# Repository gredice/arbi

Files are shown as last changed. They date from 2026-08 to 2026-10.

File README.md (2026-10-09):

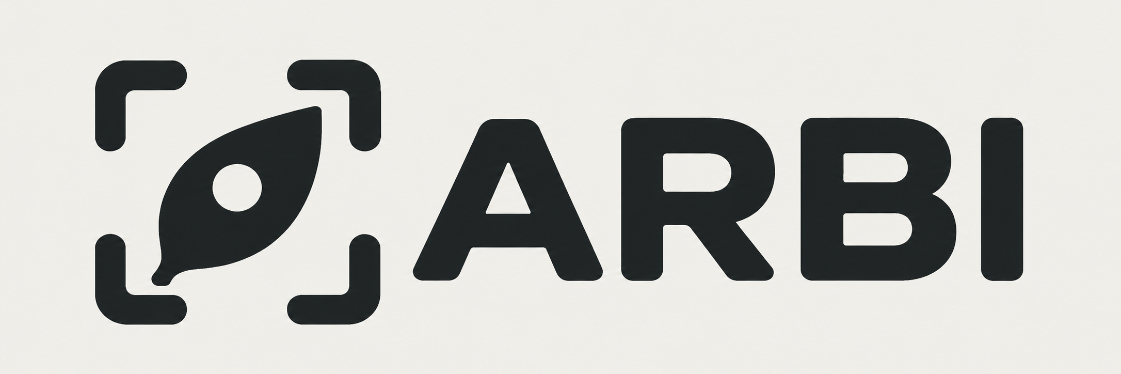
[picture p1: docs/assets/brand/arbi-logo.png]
ARBI Garden Focus logo: a leaf and lens inside a viewfinder


# ARBI

The Automatic Raised Bed Imaging system, is an open engineering project for a four-cable outdoor camera robot. This GitHub repository is the sole source of truth for the project. Its committed files and Git history define the documentation, parametric OpenSCAD models, bill of materials, software, tests, and design decisions; GitHub issues and pull requests hold the corresponding work and review history.

The current material is a **concept and design baseline**. It is not evidence of a built, certified, or safe installation. See the [design status](docs/project/design-status.md) and [safety case](docs/system/safety-case.md) before using any design information.

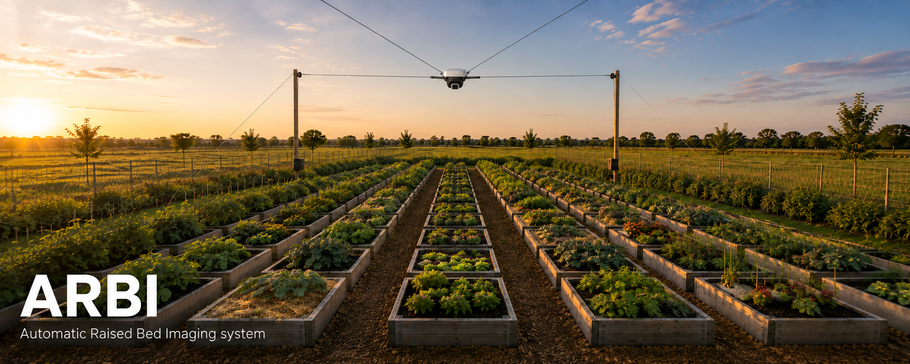
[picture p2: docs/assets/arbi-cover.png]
ARBI Automatic Raised Bed Imaging system over raised garden beds


*Scenic concept imagery using the [selected payload design language](docs/project/industrial-design.md); not a built installation.*

## Start here

- [Engineering documentation](docs/README.md)
- [Goals and V1 scope](docs/project/goals-and-v1-scope.md)
- [System architecture](docs/system/architecture.md)
- [Current design status](docs/project/design-status.md)
- [Industrial design conventions](docs/project/industrial-design.md)
- [Official logo and brand guide](docs/project/brand-identity.md)
- [Repository source-of-truth policy](docs/project/repository-source-of-truth.md)
- [Hardware and OpenSCAD sources](hardware/README.md)
- [BOM data and generated reports](bom/README.md)
- [Contributing](CONTRIBUTING.md)

## Repository map

- `docs`: requirements, architecture, physical assemblies, operations, decisions, and evidence policy.
- `hardware`: canonical OpenSCAD sources, shared modeling helpers, model metadata, and hardware-specific notes.
- `bom`: canonical part, assembly, supplier, offer, destination, and build data plus generated reports.
- `packages/arbi-bom`: BOM schemas, deterministic landed-cost calculation, generation, and validation.
- `apps/arbi-docs`: public site at [arbi.gredice.com](https://arbi.gredice.com), compiled from the files above at build time.
- `scripts`: repository-level validation that does not belong to one package.
- `.github`: public contribution templates and secret-free continuous integration.

The documentation is organized by physical assembly: [corner support set](docs/assemblies/corner-station/README.md), [camera pod](docs/assemblies/camera-pod/README.md), [dock](docs/assemblies/dock/README.md), [control cabinet](docs/assemblies/control-cabinet/README.md), and [site installation](docs/assemblies/site-installation/README.md). The [winch set](docs/assemblies/winch/README.md) is a corner-support subassembly and owns the four lines, with a shared [positioning-line specification](docs/assemblies/positioning-lines/README.md). Mechanical parts, electronics, wiring, fasteners, printed parts, software interfaces, tests, and maintenance information belong to their owning assembly rather than to component-type subsystems.

## Local setup

Requirements:

- Node.js `>=24` (`.nvmrc` pins the current development release)
- Corepack and the pnpm version pinned in `packageManager`
- OpenSCAD `2021.01` for local geometry compilation; static CAD validation still runs when OpenSCAD is absent

```bash
corepack enable
pnpm install
pnpm docs:check
pnpm bom:check
pnpm cad:check
pnpm lint
pnpm typecheck
pnpm test
pnpm build
```

`pnpm cad:check` compiles every registered model when `openscad` is available. CI requires OpenSCAD and always performs compilation. Generated STL, 3MF, and CSG files are derived artifacts and are not committed.

Use `pnpm bom:generate` after changing canonical BOM inputs. Generated Markdown and JSON reports are tracked so GitHub readers can inspect a deterministic build calculation. CI rejects missing or stale generated reports.

See [WORKSPACE.md](WORKSPACE.md) for boundaries, commands, generated artifacts, and the planned software layout.

## Planned monorepo growth

Deployable software will be added only with an implemented, testable slice. Expected destinations are:

- `apps/arbi-simulator`: simulator executable or interface;
- `apps/arbi-edge-controller`: local orchestration and control adapter;
- `apps/arbi-cloud`: remote request, telemetry, and image integration if required;
- `apps/arbi-pod-firmware` and `apps/arbi-control-cabinet-firmware`: hardware targets when their toolchains and boundaries are selected;
- `packages/arbi-protocol`, `packages/arbi-control`, and `packages/arbi-simulation-core`: shared contracts and pure logic when reuse is real.

Empty placeholder applications are intentionally omitted. The [simulator decision](docs/decisions/0004-simulator-boundary.md) preserves the required contract boundary without claiming an implementation exists.

## Contributing and safety

Contributions are welcome through GitHub issues and pull requests. Changes that affect loads, mains wiring, motion, line clearance, docking, control authority, or fault behavior must state their safety impact and validation evidence. CAD compilation, simulation, bench testing, installed-system testing, and safe public operation are separate evidence levels.

Read [CONTRIBUTING.md](CONTRIBUTING.md), [GOVERNANCE.md](GOVERNANCE.md), [SECURITY.md](SECURITY.md), and the [Code of Conduct](CODE_OF_CONDUCT.md) before contributing.

## License

Unless an individual file explicitly states otherwise, all source code, OpenSCAD hardware sources, documentation, BOM files, and other repository materials are licensed under the [GNU Affero General Public License v3.0 only](LICENSE). This matches the Gredice monorepo license and keeps the planned V1 merge path explicit.

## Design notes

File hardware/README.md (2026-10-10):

# ARBI hardware sources

This directory contains the canonical parametric OpenSCAD sources for custom ARBI parts and illustrative models of catalog items. Every current model is a **concept-unvalidated** starting point: it has not been proven dimensionally compatible, printable, structurally adequate, weather-resistant, or safe for an installed system.

The shared helpers use [BOSL2 v2.0.766](vendor/BOSL2/README.md), vendored with its
license, upstream commit and source hashes. No global library installation is
required. The guide documents current uses, anchoring and rounding conventions,
portable source packs and the upgrade process.

## Model index

The machine-readable registry is [models.json](models.json). It declares stable model IDs, design revisions, source entrypoints, owning assemblies, documentation, status, and release output names.

| Model | Assembly | Revision | Purpose |
| --- | --- | --- | --- |
| `winch-drum` | [Winch](assemblies/winch/README.md) | `2.1.0` | Segmented drum assembly reference |
| `winch-drum-passive-1/2`, `winch-drum-powered-1/2/3` | [Winch](assemblies/winch/README.md) | `0.1.0` | Five variant-specific grooved body sections |
| `winch-drum-flange`, `winch-drum-flange-right`, `winch-drum-clamp-half`, `winch-drum-tail-clamp`, `winch-drum-alignment-pin` | [Winch](assemblies/winch/README.md) | `0.1.0` | Shared drum fabrication components |
| `winch-mount` | [Winch mount](assemblies/winch/mount.md) | `0.1.0` | Passive/powered mount assembly and base drilling reference |
| `winch-bearing-lower`, `winch-bearing-cap`, `winch-motor-stand`, `winch-coupling-guard` | [Winch mount](assemblies/winch/mount.md) | `0.1.0` | Bearing supports, adjustable motor stand and coupling cover |
| `camera-pod-envelope` | [Camera pod](assemblies/camera-pod/README.md) | `0.1.0` | Non-manufacturing pod and motion keep-out reference |
| `camera-pod-assembly` | [Camera pod](assemblies/camera-pod/README.md) | `0.3.5` | Canonical non-manufacturing enclosed camera-pod reference |
| `camera-pod-spider` | [Camera pod](assemblies/camera-pod/README.md) | `0.1.0` | Four-line load-interface spider concept |
| `camera-pod-electronics-mount`, `camera-pod-docking-stud`, `camera-pod-line-strain-relief` | [Camera pod](assemblies/camera-pod/README.md) | `0.1.0` | Fixed electronics plate, mushroom stud and line fairleads |
| `camera-gimbal-base`, `camera-gimbal-yoke`, `camera-gimbal-camera-plate`, `camera-gimbal-rain-cap`, `camera-gimbal-optical-hood` | [Camera pod](assemblies/camera-pod/README.md) | `0.1.0` | Two-axis gimbal fabrication set |
| `dock-funnel` | [Dock](assemblies/dock/README.md) | `0.1.0` | Passive conical alignment funnel concept |
| `dock-nest` | [Dock](assemblies/dock/README.md) | `0.1.0` | Pod locating nest and mounting plate concept |
| `top-pulley-keeper` | [Corner station](assemblies/corner-station/README.md) | `0.1.0` | Line-retention keeper around the top pulley concept |

Fabrication models identify their canonical BOM part IDs in the registry. The winch-drum assembly, winch-mount, camera-pod envelope, and camera-pod assembly are `reference` artifacts with no BOM part IDs and export CSG. Individual drum, mount, camera-pod chassis, and gimbal components export fabrication STL and map to their BOM parts. All models remain concept-unvalidated.

Every BOM catalog item has at least one active model. Purchased items, materials,
consumables and custom items without manufacturing sources have `visualization`
STLs. These carry explicit `geometry.status: approximate`, dimension assumptions
and rework requirements in the registry, source header and assembly README. Their
shape is not yet fully defined. They need supplier drawings or measurements and
model rework before fit, clearance or fabrication decisions. Visualization STL
does not establish a manufacturing source, even for a planned custom item.
Assortments show samples rather than pack contents; cables show samples rather
than installed length or routing. Shared purchasing samples live in
[shared procurement stock](assemblies/shared-procurement-stock/README.md).

## Validation

From the repository root:

```bash
pnpm cad:check
pnpm cad:check -- --require-openscad
```

The first command always validates registry metadata against its JSON Schema, checks source files, documentation links, relative OpenSCAD dependencies, bidirectional BOM fabrication-source traceability, and the exact pinned OpenSCAD version when the CLI is present. It compiles all registered models when `openscad` is installed. The second command requires the CLI and compilation and is the CI path. Both compile paths require OpenSCAD `2021.01`; a different installed version fails explicitly so model outputs are not presented as reproducible across an untracked toolchain change.

Compilation writes declared STL fabrication and visualization meshes and CSG reference artifacts into a temporary directory and removes it afterward. Generated STL, 3MF, CSG, and bulk render output are not committed. A successful compile proves only that source geometry can be evaluated.

## CAD downloads

[GitHub Releases](https://github.com/gredice/arbi/releases) publishes a complete CAD snapshot whenever OpenSCAD sources, the model registry, booklet inputs or CAD publication tooling change on `main`. New releases use `cad-vMAJOR.MINOR.PATCH`, starting at `cad-v0.1.0` and automatically incrementing the highest published or reserved patch version. A manual workflow dispatch can request a higher minor or major version. These are snapshot versions; each model keeps its own design revision and evidence status. Existing `cad-<full commit SHA>` releases remain historical records.

Each release includes every registered STL fabrication part, approximate visualization STL, CSG reference assembly, hardware source ZIP, all three assembly booklets and packs, the complete CAD preview pack, and SHA-256 checksums. `cad-release.json` records the exact source commit, model revisions and CAD/booklet/preview input hashes. Publication first uploads a draft, then publishes the complete release. Retrying a published source commit reuses its immutable version and retries the site refresh. Latest follows source commit ancestry, so rerunning an older commit cannot replace a newer source release even if it receives a higher snapshot version.

Production site builds require the release inputs to match their checkout and all registered outputs to be present. Publishing Latest calls the required `ARBI_SITE_DEPLOY_HOOK` secret and verifies that [arbi.gredice.com](https://arbi.gredice.com) serves the current release or a subsequent one within ten minutes. A missing hook, failed request or failed verification fails the workflow visibly; rerun it to retry. While new geometry is being built, a premature Vercel production build fails and the last successful site remains live until the release-triggered rebuild succeeds. A release does not establish that a part is physically safe to build or install.

To keep compiled files locally, pass an empty output directory: `pnpm cad:check -- --require-openscad --output-dir /path/to/empty-directory`.

## Adding a model

1. Read [conventions.md](conventions.md).
2. Put reusable modules in `lib` and assembly-owned entrypoints in `assemblies/<assembly>`.
3. Add one registry entry per intended output in `models.json`.
4. Document purpose, default parameters, interfaces, known omissions, and required validation beside the model.
5. Run the required CAD check and review the generated geometry visually before proposing a release.

The system requirements and evidence status live in the matching documents under [`docs/assemblies`](../docs/assemblies).

The [winch mount family](assemblies/winch/mount.md) adds a bearing lower, bearing
cap, motor stand and coupling cover (0.1.0), with a passive/powered assembly
reference. Metal base stock is a drilling proposal, not a printed release part.

## Archived models

`models.json` separates active `models` from `archivedModels`. Archived entries retain stable IDs, revisions, evidence status, source paths, an archive reason and current replacement IDs. They have no BOM ownership, active inventory count, individual release mesh, preview or fabrication download. CAD validation still checks their source/includes so historical references cannot silently break.

The camera-pod archive covers the original concept kit and keep-out, six dry bench-only alternatives, and the retired fixed fairing, tilt-servo boot and rear camera cowl. The compact `camera-pod-integrated-deck` is current; `camera-pod-electronics-deck` is the dry bench alternative. The shared spider, spacers, pan mount and horn retainers remain active. Docking-stud and line-termination concepts have no selected replacement; archiving them does not resolve those interfaces.

The explicit dry bench booklet opts into only the archived entries marked `alternativeConfiguration: camera-pod-bench`; it is labeled as an alternative and does not add parts to the current compact enclosure BOM or assembly. The enclosure exports 13 fabrication models (12 installed types plus the optional servo fit coupon) and installs 16 printed pieces. Other committed model families retain their documented optional configurations and variants; an unmerged replacement proposal does not supersede them.

## Camera-pod naming compatibility

All current camera-pod CAD IDs, source/module names and new booklet artifacts use `camera-pod`. The [alias map](model-aliases.json) records the former `payload-*` public IDs, including both retired assembly aliases for the single `camera-pod-assembly` reference. Old website part links redirect permanently to their current active or archived detail page. Fabrication revisions and installed quantities do not change with this rename; BOM part IDs remain stable.

Dated inspection JSON and committed PDF/ZIP snapshots retain the observed model names, filenames and hashes. Their names identify historical evidence, and do not register duplicate current models. New CAD releases and enclosure/bench booklets are regenerated from the canonical sources. Generic software message payloads retain their protocol meaning.

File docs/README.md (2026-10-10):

# ARBI engineering documentation

ARBI is an outdoor four-cable camera robot for repeatable images of raised beds. This documentation is organized by physical assembly so that each assembly owns its mechanics, electronics, cabling, fasteners, printed parts, software, tests, and maintenance information.

The committed material is a **design baseline**, not proof of a built or safe installation. Values described as targets or starting points remain unverified until an acceptance record is committed and linked from the relevant document. The repository and its GitHub records are the project's only authority; see the [repository source-of-truth policy](project/repository-source-of-truth.md).

## Start here

- [Goals and V1 scope](project/goals-and-v1-scope.md)
- [Current design status](project/design-status.md)
- [Industrial design conventions](project/industrial-design.md)
- [Official logo and brand guide](project/brand-identity.md)
- [System architecture](system/architecture.md)
- [Site geometry](system/site-geometry.md)
- [Interfaces and operating states](system/interfaces-and-operating-states.md)
- [Safety case](system/safety-case.md)
- [Local safety interface matrix](system/local-safety-interface-matrix.md)
- [Prototype and commissioning plan](operations/prototype-and-commissioning.md)
- [Repository source-of-truth policy](project/repository-source-of-truth.md)

## Physical assemblies

- [Site installation](assemblies/site-installation/README.md)
- [Corner support set](assemblies/corner-station/README.md), including the [winch set](assemblies/winch/README.md) and its ordinary/powered positioning lines
- [Camera pod](assemblies/camera-pod/README.md)
- [Dock](assemblies/dock/README.md), with a proposed [compact-pod interface package](assemblies/dock/design-package.md),
  [bench plan](assemblies/dock/bench-test-plan.md) and [blank acceptance record](assemblies/dock/acceptance-record.md)
- [Control cabinet](assemblies/control-cabinet/README.md)

## Shared assembly specifications

- [Positioning-line specification](assemblies/positioning-lines/README.md): construction, terminations, inspection and replacement of winch-owned lines

## Components and procurement

- [Bill of materials](../bom/README.md)
- [Individual BOM item pages](../bom/generated/parts/README.md)

## Operations

- [Imaging and calibration](operations/imaging-and-calibration.md)
- [Weather, parking, and maintenance](operations/weather-parking-and-maintenance.md)
- [Prototype and commissioning](operations/prototype-and-commissioning.md)

## Decision records

- [ADR-0001: Organize engineering information by physical assembly](decisions/0001-physical-assembly-taxonomy.md)
- [ADR-0002: Treat OpenSCAD files as canonical model sources](decisions/0002-openscad-canonical-sources.md)
- [ADR-0003: Separate parts, assembly quantities, and supplier offers](decisions/0003-bom-separation.md)
- [ADR-0004: Share contracts between hardware control and simulation](decisions/0004-simulator-boundary.md)
- [ADR-0005: Software architecture and deployment boundaries](decisions/0005-software-architecture-and-deployment.md)
- [ADR-0006: Local safety authority and instrumentation](decisions/0006-local-safety-authority-and-instrumentation.md)
- [ADR-0007: Integrated product design](decisions/0007-integrated-product-design.md)
- [ADR-0008: Edge host and bounded local transport](decisions/0008-edge-host-and-local-transport.md)
- [ADR-0009: Compact integrated camera pod packaging](decisions/0009-compact-integrated-camera-pod.md)
- [ADR-0010: Corner support and winch-line ownership](decisions/0010-corner-support-and-winch-line-ownership.md)

## Software evidence

- [Transport capability review and bounded local recovery experiment](evidence/software-transport-feasibility.md)
- [Protocol 1.0 contracts, semantic rules and host reference-test boundary](software/protocol.md)
- [Configuration 1.0, calibration identity and transactional apply/rollback reference boundary](software/configuration.md)
- [Authorized site commissioning, multi-device staging and deliberate recovery](software/commissioning.md), with [host evidence](evidence/commissioning.md)
- [Mobile data accounting 1.0 contracts, boundary rules and executable worked fixtures](software/mobile-data-accounting.md)
- [Device transfer instrumentation, durable raw counters and explicit Linux/router coverage](software/device-traffic-metering.md), with [host evidence](evidence/device-traffic-metering.md)
- [Durable usage ingestion, billing-period rollups and explicit accounting uncertainty](software/usage-rollups.md), with [host evidence](evidence/usage-rollups.md)
- [Edge transfer budgets, essential traffic bounds and verified artifact recovery](software/transfer-budgets.md), with [host evidence](evidence/transfer-budgets.md)
- [Cross-runtime reference vectors, independent host consumers and offline workspace checks](software/reference-fixtures.md)
- [Scenario 1.0 contracts, deterministic offline runner and independent host evidence](software/scenarios.md)
- [Bounded plant/module model 1.0, virtual sensors and independent host evidence](software/bounded-plant-model.md)
- [Gredice identity, site permissions and executable request authorization boundary](software/site-authorization.md)
- [Audit 1.0 vocabulary, privacy and evidence semantics](software/audit-events.md)
- [Deferred recording, playback, custody and retention activation policy](software/recording-policy.md)
- [Transactional audit admission, SQLite spool and deduplicated ingestion](software/audit-durability.md)
- [Release/update 1.0 manifests, mixed-version paths and pure recovery reference](software/release-updates.md)
- [Gated web builds, immutable Linux application releases and read-only dashboard catalog](software/software-publication.md)
- [Device enrollment, inventory and credential lifecycle with isolated PostgreSQL evidence](software/device-enrollment.md)
- [Image metadata, private Blob direct grants, lifecycle cleanup and isolated PostgreSQL/HTTP evidence](software/image-storage.md)
- [Durable cloud command jobs, exclusive manual leases and isolated PostgreSQL/HTTP evidence](software/command-jobs.md)
- [Current state, bounded telemetry/event history and configured assembly inventory](software/telemetry-history.md), with [host evidence](evidence/telemetry-history.md)
- [Outbound realtime routing, scoped Ably SDK tokens and commit-safe authoritative recovery](software/realtime-recovery.md), with [host evidence](evidence/realtime-recovery.md)
- [Authenticated user/engineering dashboard shell, explicit synthetic test provider and setup](software/dashboard-shell.md), with [dated source/hosted evidence](evidence/dashboard-shell.md)
- [Supervised edge runtime, local framing and diagnostic authority](software/edge-runtime.md), with [development-host evidence](evidence/edge-runtime-prototype.md)
- [Local manual-control fences and independent deadman](software/manual-control.md), with [host/simulation evidence](evidence/manual-control.md)

## Evidence language

These labels are used throughout the documentation:

- **Requirement** — behavior or constraint the design must satisfy.
- **Baseline** — the current V1 design choice recorded in the repository.
- **Target** — a value the design aims to achieve but has not yet demonstrated.
- **Starting point** — an initial test value that must be tuned from measured results.
- **Unverified** — a claim or selection that still needs analysis, inspection, or testing.
- **Deferred** — intentionally outside the first prototype or V1 baseline.
- **Validated** — supported by a named test record, calculation, or inspection result committed to the repository.

Do not change a claim to **Validated** in prose alone. Link the evidence and record the tested revision, configuration, conditions, equipment, result, and reviewer.

## Documentation ownership

Cross-discipline item types are not separate subsystems. A fastener used on a winch belongs to the winch assembly; a cable from the cabinet to a corner has named endpoints and an owning interface. Shared standards may describe conventions, but the assembly documentation owns quantities, fit, routing, acceptance, and maintenance.

Design decisions belong in ADRs. Work items and unresolved questions belong in GitHub issues, with links back to the affected document. Procurement data belongs in the repository BOM rather than being copied into prose. Private notes, chats, external pages, spreadsheets, and dashboards are not project records.

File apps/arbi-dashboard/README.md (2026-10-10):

# ARBI dashboard and HTTP boundary

This Next.js app implements the [authenticated dashboard shell](../../docs/software/dashboard-shell.md) for [#39](https://github.com/gredice/arbi/issues/39), simulation-only [device enrollment and inventory boundary](../../docs/software/device-enrollment.md) for [#21](https://github.com/gredice/arbi/issues/21), and [image metadata/private storage boundary](../../docs/software/image-storage.md) for [#22](https://github.com/gredice/arbi/issues/22). It contains working HTTP handlers, protected PostgreSQL migrations, identity/proof verification, a Vercel private Blob SDK adapter and lifecycle tests. The [durable command job and exclusive manual lease boundary](../../docs/software/command-jobs.md) implements #28. [Outbound realtime and authoritative recovery](../../docs/software/realtime-recovery.md) implements the source/host slice of #29. Detailed diagnostics, live provider provisioning, live media and physical device adapters remain separate work.

The shell serves site-scoped user/engineering pages and protected `/api/sites/:siteId/dashboard/:view` reads. [Setup, contract, isolated provider and browser commands](../../docs/software/dashboard-shell.md) describe the boundary; [source/hosted evidence](../../docs/evidence/dashboard-shell.md) keeps test deployment separate from production. Ordinary starts remain unconfigured. The explicit isolated test provider uses current PostgreSQL sessions/memberships and the committed bounded plant model; it never grants commands or live-device authority.

The mounted route is `/api/sites/:siteId/enrollment/:action`. An unconfigured build returns a redacted `503`; it never installs a fixture identity provider or an in-memory registry by default. Trusted server composition uses [createEnrollmentServer](src/enrollment/server.ts) with the accepted Gredice identity/current directory/resource resolver, approved browser origins and a migrated database, then [configureEnrollment](src/enrollment/runtime.ts). The resource resolver and directory are current server-side adapters, never body-supplied roles or site claims. This initial slice rejects production and hardware scope.

Media routes are `/api/sites/:siteId/media/:action` and `/api/sites/:siteId/images/:imageId/:action`; they also fail closed until explicitly installed via [createMediaServer](src/media/server.ts)/[configureMedia](src/media/runtime.ts). The service provides strict upload metadata, retry-safe direct PUT grants, idempotent verified completion, original/thumbnail access, revocation records and repeatable deletion/cleanup. [Media documentation](../../docs/software/image-storage.md) specifies exact JSON bodies, trusted capture provenance, signed URL expiry/revocation limits, stored-payload accounting, operational cleanup/retention requirements and remaining live gates. Apply [0002-media.sql](migrations/0002-media.sql) explicitly with `pnpm --filter @arbi/dashboard db:migrate:media` and privately supplied `ARBI_MEDIA_DATABASE_URL`; `0001` and its command are unchanged. Provision authoritative media-site bindings separately; never derive ownership from request claims or enable fixture fallbacks.

[postgresDatabase](src/enrollment/store.ts) uses a server-side `pg.Pool` for the selected Neon PostgreSQL boundary. Configure pooled connections with a bounded connection timeout; no provider URL or credential is supplied in this repository. Run the [migration](migrations/0001-enrollment.sql) explicitly via `pnpm --filter @arbi/dashboard db:migrate` with `ARBI_ENROLLMENT_DATABASE_URL` supplied privately. No migration or commissioning happens during build/start. Provision the initial simulated inventory through the protected `simulationRegistry`/`PostgresRegistryStore.provision` server interface using validated configuration and the account from the authoritative site catalog. Existing rows cannot be overwritten by bootstrap.

```sh
pnpm install --frozen-lockfile
pnpm --filter @arbi/protocol build
pnpm --filter @arbi/gredice build
pnpm --filter @arbi/dashboard lint
pnpm --filter @arbi/dashboard typecheck
pnpm --filter @arbi/dashboard test
pnpm --filter @arbi/dashboard test:postgres
pnpm --filter @arbi/dashboard build
pnpm --filter @arbi/dashboard test:http
```

The ordinary suite uses embedded PostgreSQL (PGlite), temporary synthetic configuration, ephemeral device keys and a loopback HTTP Blob fixture that exercises the real SDK without cloud credentials. The separate `test:postgres` requires `pg_config`, `initdb`, `pg_ctl` and local socket/loopback access. It creates/removes its own temporary PostgreSQL cluster, disables TCP listening, and tests independent connections, migration preservation and transaction rollback for enrollment and media. After build, `test:http` starts/stops its own loopback Next.js server and verifies unprovisioned enrollment/media responses stay redacted and fail closed. CI invokes all three. The ordinary suite marks host-specific tests skipped unless the dedicated launcher supplies its isolated socket; this is not a substitute for running `test:postgres`.

Ordinary fixture files run sequentially to avoid competing database startup starving bounded loopback requests. This finite test process also disables **WebAssembly code** garbage collection with `--no-wasm-code-gc`: Node 24.15.0 Linux CI aborted in V8's `UnregisterWasmAllocation` with `jit_page_->allocations_.erase(addr) == 1`. The signature matches [Node issue #66366](https://github.com/nodejs/node/issues/66366) and the [upstream V8 wrapper lifetime fix](https://github.com/v8/v8/commit/9b8ca54d5a). This is a test-only workaround that retains compiled Wasm code until process exit; JavaScript garbage collection, assertions and request deadlines remain unchanged. Remove the flag after the pinned Node release includes the fix and repeated Linux fixture runs pass without it. Application `dev`/`start`/`build` and the native PostgreSQL/HTTP launchers do not use this flag; PGlite is a development dependency.

`pnpm --filter @arbi/dashboard start` serves a built, fail-closed app. Source tests and local database checks do not establish live Gredice/Neon provisioning, Vercel team deployment, power-loss durability, installed commissioning, safe actuation or physical acceptance. Those gates remain unverified.

## Durable audit foundation

The [audit adapter](src/audit/server.ts) adds signed device ingestion at `/api/sites/:siteId/audit/ingest`, transactional cloud intent/authorization/outbox admission and protected append-only history. It requires explicit server composition with current enrollment and an independently trusted event-ID evidence resolver; missing configuration returns 503. Device ingestion remains simulation-only under current enrollment. Apply additive `0003-audit.sql` after unchanged 0001/0002 with `pnpm --filter @arbi/dashboard db:migrate:audit` and operator-only migration credentials. Never use migration ownership as the application role.

[Audit durability](../../docs/software/audit-durability.md) owns roles, replay/clock/gap semantics, checkpoint/backup threat limits and host evidence. Shared [SQLite local APIs](../../packages/arbi-audit/README.md) remain independent of edge job orchestration. `test:postgres` preserves independent enrollment/media suites and runs native audit tests in a separate database within its fresh socket-only cluster. This does not deploy provider resources, enable recording or clear physical safety gates.

## Durable command jobs and manual sessions

Mounted `/api/sites/:siteId/jobs/:action` handlers implement persisted intent/status, exclusive fenced human leases, signed receiver snapshots, bounded device polling and immutable protocol outcome receipts. [createJobsServer](src/jobs/server.ts)/[configureJobs](src/jobs/runtime.ts) require explicit trusted current identity/resource/session authorization and migrated storage. Missing configuration denies every action. Apply additive [0004-jobs.sql](migrations/0004-jobs.sql) after unchanged 0001/0002/0003 via `db:migrate:jobs` with privately supplied `ARBI_JOBS_DATABASE_URL`. Admission uses the existing transactional audit/outbox hook.

[Command job documentation](../../docs/software/command-jobs.md) specifies exact bodies, resolver requirements, restart/clock/fence semantics, cancellation versus independent stop receipts, status provenance and remaining gates. Native `test:postgres` runs its independent-connection/crash/replay/rollback proof; built `test:http` checks all mounted job/lease actions fail closed. This is a simulation-only cloud boundary, with no broker, local job orchestration, provider provisioning or physical enablement.

## Outbound realtime recovery

Mounted `/api/sites/:siteId/realtime/:action` supports human attach/recover and signed current-device attach/recover. Explicit [server composition](src/realtime/server.ts)/[runtime installation](src/realtime/runtime.ts), current authorization, migrated storage and private Ably SDK adapter are required. Apply additive [0005-realtime.sql](migrations/0005-realtime.sql) after 0001–0004 with `db:migrate:realtime`; configure bounded operator `realtime:maintain` scheduling separately. [Semantics, roles, limits and exact external gates](../../docs/software/realtime-recovery.md) and [host evidence](../../docs/evidence/realtime-recovery.md) distinguish source/SDK fixtures/native PostgreSQL from actual Ably/Neon/Vercel/mobile acceptance. Build the edge consumer before running native `test:postgres`; root `pnpm test --concurrency=1` and CI already build it. No fixture server or identity is a deployment default.

The opt-in [browser consumer](src/realtime/browser-consumer.ts), [HTTPS adapter](src/realtime/browser-http.ts) and [Ably browser subscription](src/realtime/browser-ably.ts) use the same authoritative API. Trusted composition supplies the current ARBI bearer; page teardown aborts recovery and clears state. Hints coalesce, replay gaps reset, broker downtime permits bounded HTTPS recovery, and request/admission/application-byte budgets apply. The shell does not start this client by default. `pnpm --filter @arbi/dashboard test:browser` includes actual Chromium/SDK/native PostgreSQL recovery and revocation checks alongside the shell tests; install the pinned Chromium with `pnpm --filter @arbi/dashboard exec playwright install chromium` first.

## Current telemetry and bounded history

The [telemetry adapter](src/telemetry/server.ts) mounts signed device ingestion and protected current/history/configured-assembly inventory queries at `/api/sites/:siteId/telemetry/:action`. It retains boot/sequence/configuration and sample provenance, visible gaps/resets, explicit unavailable/stale values, quality-separated minute/hour aggregates, full event/fault detail and small private trace attachments. Current state and replay/outbox hints commit together. Trusted server composition is explicit and simulation-only; an ordinary start returns unavailable.

Apply additive [0006-telemetry.sql](migrations/0006-telemetry.sql) after migrations 0001–0005 using `pnpm --filter @arbi/dashboard db:migrate:telemetry`. [Telemetry history](../../docs/software/telemetry-history.md) specifies API fields, retention/row/byte/request/query budgets, role grants and `telemetry:maintain` for idle sites. The ordinary and native PostgreSQL suites include the committed [telemetry evidence](../../docs/evidence/telemetry-history.md); `test:http` checks the mounted fail-closed routes. Provider provisioning and physical acceptance remain separate.

## Usage ingestion and rollups

The [usage adapter](src/usage/server.ts) mounts `/api/sites/:siteId/usage/:action` for signed bounded source-window admission, current-authority history/period reads and audited append-only corrections. It requires explicit trusted [runtime installation](src/usage/runtime.ts) and fails closed by default and in branch previews. Apply [0007-usage.sql](migrations/0007-usage.sql) after 0001–0004 with `pnpm --filter @arbi/dashboard db:migrate:usage`; keep migration ownership separate from application privileges. [Usage documentation](../../docs/software/usage-rollups.md) specifies exact request bodies, replay/overlap semantics, layer separation, UTC days, plan-timezone periods, estimated boundary allocation, rollover and hard bounds. [Host evidence](../../docs/evidence/usage-rollups.md) separates embedded SQL from native audit/concurrency checks and actual cellular/provider acceptance.

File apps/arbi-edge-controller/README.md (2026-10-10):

# ARBI edge controller

Executable **development-host prototype** for [#23](https://github.com/gredice/arbi/issues/23), implementing [ADR-0008](../../docs/decisions/0008-edge-host-and-local-transport.md). It runs only an isolated `test` realm in `simulation` mode. Diagnostic readiness never enables physical actuation, updates or recording. It implements local connection supervision and bounded state/telemetry admission; optional local jobs, commissioning and cloud recovery are described below; real firmware remains follow-up work.

## Run from the repository root

Use Node.js 24.15.0 (repository minimum 24), pinned pnpm and OpenSSL for disposable test certificates:

```sh
pnpm install --frozen-lockfile
pnpm build
pnpm --filter @arbi/edge-controller simulate
```

The process generates a private temporary certificate directory, starts two loopback test peers and prints one JSON startup record containing an ephemeral `healthPort` and fresh edge identity. Read `http://127.0.0.1:<healthPort>/healthz` and `/readyz`. Send SIGINT or SIGTERM to close sockets, cancel reconnects, stop the peers and remove temporary credentials. Keys, certificates and configuration paths are never printed. Abrupt process termination may leave its private temporary directory; remove that disposable directory locally after stopping its processes. No generated credential belongs in Git.

`/healthz` returns 200 while the process serves requests. `/readyz` returns 503 until both authenticated peers provide compatible current snapshots, and again on disconnect, expiry or shutdown. Both expose build source digest/version, protocol, new boot/session identity, exact accepted applied configuration identity, module identities, inhibits and configured capabilities. The build digest includes app sources, compiler settings, dependency lockfile, Linux service definition, protocol schemas and built protocol consumers. The historical `appliedBy` remains distinct from the current boot identity. Health binds loopback and limits connections/headers. The default runtime accepts only GET health/readiness; trusted commissioning composition can add the separately authenticated routes described below.

For externally hosted synthetic peers, a private `arbi.edge/1.0` manifest specifies the bounded applied configuration record, independently accepted configuration digest, the edge's certificate file paths and exactly two local enrollment entries. Entries bind module ID/role, loopback port, DNS certificate name and certificate SHA-256. There is no discovery of arbitrary network addresses or trust-on-first-use enrollment. `createSimulation()` in [simulation.ts](src/simulation.ts) produces the executable reference manifest from the committed protocol fixture. Invalid, oversized, unsupported, non-test or hardware configuration exits 78 before opening health or module sockets. This loader only restores a previously accepted synthetic record; optional commissioning is a separate trusted composition.

```sh
node apps/arbi-edge-controller/dist/cli.js --config /absolute/private/simulation.json
node apps/arbi-edge-controller/dist/supervisor.js --config /absolute/private/simulation.json
```

The second command is a portable child-process supervision prototype: at most five starts per minute, 250 ms retry delay on crash, no retry for exit 0 or invalid configuration (78), SIGTERM then SIGKILL after five seconds on shutdown. It has no command journal and replays no commands. Linux uses [the systemd unit](deploy/arbi-edge-controller.service), not the development supervisor. The `/opt/arbi` and `/etc/arbi-edge` paths are installation templates, not a private deployment. An operator must stage the immutable repository build and Node 24 runtime at the declared paths, create the dedicated unprivileged account, and supply private synthetic configuration/credentials before starting it. See the ADR for privileged installation, service confinement and the unfulfilled selected-host acceptance gate.

## Adapter boundary

See [the transport specification and evidence](../../docs/software/edge-runtime.md). `ModuleAdapter` connects using TLS 1.3 mutual authentication and certificate pinning. A fresh challenge, source identity, protocol, test realm/site and accepted configuration digest precede the initial snapshot. Discovery verifies existing enrollment; it cannot grant new trust. The prototype exposes only `state.resync`, authorized explicitly to the synthetic `simulation-diagnostics` service through a bounded, single-use grant. TLS host identity is never human authority. No human permission, UI mode, cloud grant or opaque object can enable actuators here.

The simulated module independently admits that diagnostic command through `@arbi/protocol`. Source/configuration/capability/cursor checks apply to received snapshots and telemetry. Configured unavailable readings retain empty capability qualities; driver encoders and line tension do not become measured data. The simulated module remains locally inhibited and its local stop function has no edge/cloud dependency. This is a source boundary demonstration, not proof of independent physical stopping or a firmware watchdog.

## Validation

```sh
pnpm --filter @arbi/edge-controller lint
pnpm --filter @arbi/edge-controller typecheck
pnpm --filter @arbi/edge-controller test
pnpm --filter @arbi/edge-controller build
pnpm protocol:check
pnpm docs:check
git diff --check
```

Tests require loopback listening, child processes and OpenSSL. Linux additionally requires `systemd-analyze` and the same Node version staged at the unit's declared `/usr/bin/node` path; CI provisions that path explicitly before verifying the unmodified unit. They use disposable synthetic credentials, the current configuration fixture and protocol message vectors. The [committed evidence record](../../docs/evidence/edge-runtime-prototype.md) identifies what was run and which Linux, hardware and physical gates remain unverified.

## Traffic metering

Optional private `metering` settings contain `spoolFile`, `maxRecords`, `maxBytes`, `maxPages` and `linuxLoopback`. Omission is explicitly `not-configured`; there is no implicit production path. Place the file in the service's private `StateDirectory=arbi-edge` when configured. The synthetic `--simulate` consumer uses temporary edge and pod SQLite files, 2,048 records/16 MiB reserved bytes/1,024 pages each, and deletes them only on fixture disposal. These starting budgets are not qualified selected-host capacity.

Authenticated module socket frames are tapped through [@arbi/traffic](../../packages/arbi-traffic/README.md); the simulated pod exercises the same library. Current endpoints and optional five-second Linux `lo` counter collection remain LAN-only. Health exposes partial application coverage, unknown UTC uncertainty, unavailable garden WAN/provider counters, and durable/volatile spool degradation. Counter/payload/provider layers remain separate. Physical actuation, readiness authorization and local stops do not depend on metering health. See [semantics](../../docs/software/device-traffic-metering.md) and [host evidence](../../docs/evidence/device-traffic-metering.md).

## Independent cloud recovery consumer

`pnpm --filter @arbi/edge-controller recover:cloud` runs [the separate diagnostic recovery executable](src/cloud-realtime/cli.ts) after build, with private protected `ARBI_CLOUD_RECOVERY_CONFIG`. [Realtime documentation](../../docs/software/realtime-recovery.md) owns exact fields, current enrollment, scoped short-lived Ably tokens, native PostgreSQL/HTTP recovery, retry/catch-up/traffic limits and the external provider/mobile gate. It does not import the local runtime, supervisor or jobs executor, cannot dispatch actuators and is never started by the existing supervisor. Snapshot/hint/job-poll receipt sends no device acceptance or completion. The [host record](../../docs/evidence/realtime-recovery.md) covers real SDK transport fixtures and a separately spawned consumer/cloud process, not a real provider account or cellular network.

## Durable local job slice

Optional bounded SQLite job storage, transactional audit intent, current local policy and an explicit bounded simulator consumer are documented in [local jobs](../../docs/software/local-jobs.md) with [host evidence](../../docs/evidence/local-jobs.md). Normal TLS enrollment remains diagnostic-only. Run the isolated reference with `pnpm --filter @arbi/edge-controller simulate:jobs --directory /tmp/arbi-isolated-jobs` after building its dependencies. Physical motion, firmware, image bytes and updates remain inhibited/unimplemented.

## Authorized commissioning

[Local commissioning](../../docs/software/commissioning.md) adds authenticated technician enrollment, independent local maintenance authorization, exact-set review, multi-device staging/activation, readiness invalidation and deliberate restart recovery. [Host evidence](../../docs/evidence/commissioning.md) covers fictional site/bed/plant framing and SIGKILL after an independent device commit. Trusted `composeCommissioning` mounts protected loopback handlers and automatically binds its inhibit to local job policy. The dashboard can read its protected identity/block-reason projection. No default runtime or private settings file creates commissioning authority. Run the explicit simulation recipe with `pnpm --filter @arbi/edge-controller simulate:commissioning --directory /tmp/arbi-isolated-commissioning`. Hardware/physical validation remains disabled.

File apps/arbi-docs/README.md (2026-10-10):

# ARBI public site

Next.js and Tailwind CSS site for [arbi.gredice.com](https://arbi.gredice.com). Its content is compiled from this repository at build time; the app holds no copies of documentation, models or BOM data.

Every page is statically generated at build time with the Next.js App Router:

| Route | Content |
| --- | --- |
| `/` | Cover with a scroll-driven teardown of the camera pod, statistics, contents and the BOM total |
| `/systems`, `/systems/[slug]` | Five physical root systems, with winch detail pages under the corner support set; each preview has numbered parts and a hover-linked inventory |
| `/systems/positioning-lines` | Permanent redirect to `/systems/corner-station`; the shared specification remains under `/docs/assemblies/positioning-lines` |
| `/systems/winch-powered` | Powered winch configuration with its own booklet pose and installed parts inventory; linked from the passive winch page |
| `/parts`, `/parts/[id]` | Every BOM item plus individual CAD components and references, grouped by owner with line-art figures, a 3D viewer, BOM links, geometry evidence and verified downloads |
| `/bom`, `/bom/[id]` | The generated BOM report and one page per catalog item |
| `/docs`, `/docs/[...slug]` | `docs/**`, `hardware/**` and `bom/README.md` rendered from Markdown with repository links mapped to site routes |
| `/downloads` | CAD release assets, archived committed booklet snapshots and per-model files with SHA-256 |

System navigation follows `parentAssemblyId`: physical roots own the numbered system links. The cover contents and Systems overview display included subassemblies beneath each parent, with configured CAD previews and parts-inventory links. The same subassembly section sits immediately below the parent system's main 3D preview. The corner system's overview shows both the pulley post head and winch previews, and its description names the three ordinary winches and one powered winch. Overview counts include the complete system with duplicate model and BOM IDs removed; prices remain on detail/BOM pages.

The [pulley post head](../../docs/assemblies/corner-head/README.md) has a `/systems/corner-head` presentation group using the existing corner-station CAD scene and a subset of its registered parts. It shares system number 01 with both winch variants. This group does not change direct BOM ownership, procurement quantities or source geometry. Parts keep their recorded direct owners, following [ADR-0010](../../docs/decisions/0010-corner-support-and-winch-line-ownership.md). Mobile navigation uses a Menu disclosure instead of a horizontally scrolling link strip; it closes after choosing a link, clicking outside or pressing Escape.

The design is the selected "Manual + Ink" direction. White manual pages use heavy rules, condensed type and booklet-style line art. Exploded views sit in full-black sections that draw the same line art inverted, with each part's role readable: white shells in pure white, the charcoal core in neutral lighter gray, bought metal in mid gray.

Code layout: `src/lib/site.ts` reads the compiled data on the server; `src/lib/markdown.ts` renders documents; `src/components/three/viewer.ts` is the three.js viewer used by the client components `CoverTeardown`, `SystemExplorer` and `PartViewer`. Links from the earlier single-page site (`#/systems/winch`) are forwarded to their routes.

Viewers show a nonblocking loading indicator while meshes arrive. Assembly parts
load independently with up to four concurrent requests and appear immediately,
including static contents previews. The camera starts from the compiled full
assembly envelope so downloading parts do not recenter the view. The camera pod
uses the booklet pack’s individual STL meshes and original millimetre transforms;
a part page downloads only its own mesh. Failed parts leave the loaded geometry
visible with an unavailable count, and leaving a page stops further queue work.

Line art combines sharp feature edges and open boundaries with camera-dependent silhouettes, so rounded surfaces keep a continuous outline while orbiting, zooming or exploding an assembly. Coplanar triangle edges stay hidden. Mesh adjacency is cached; contour buffers belong to each displayed instance and are released with the viewer.

The shaded part view uses a bounds-fitted Z-up studio with key, fill and rim
lights, filtered self shadows and a transparent floor shadow. A bundled room
environment supplies reflections for satin shells and metal parts; filmic tone
mapping keeps highlights readable. Denoised ambient occlusion adds depth to
recesses and contact points, with its resolution capped independently of the
display. The floor is excluded from CAD envelopes and
camera fitting. Lighting, shadow and environment resources are released when
switching views. Line and ink drawings keep their exact flat colors.

Embedded viewers preserve vertical touch scrolling, browser pinch zoom and
mouse-wheel page scrolling. Mouse dragging still rotates a model. The cover's
explosion follows page scrolling; assembly pages also have an explosion slider.
Four schematic suspension lines on the cover start at the spider's line holes
and extend upward out of view. They follow its exploded offset, use scene depth
for occlusion, and are excluded from CAD bounds and camera fitting.
Clicking a registered mesh opens its CAD page. The winch motor and bought
hardware open their owning BOM pages, recorded by the booklet figure manifest;
unmapped context has no navigation target.
Contents previews render their CAD scenes once at display resolution, with a
fitted camera and full-pixel outlines instead of downscaled booklet PNGs.
The scenic concept image retains its full aspect ratio, color and frame spacing.
The header and footer use the vector ARBI logo, with a white footer variant and
Gredice attribution and flags from the repository's brand assets.

## Commands

```bash
pnpm --filter @arbi/docs dev
pnpm --filter @arbi/docs build
pnpm --filter @arbi/docs typecheck
pnpm --filter @arbi/docs test
```

`dev` and `build` first run `scripts/compile-data.mjs`. It writes the ignored `public/data` from committed sources and CI-built CAD releases only:

- `hardware/models.json` supplies models, revisions, statuses, sources and release output names.
- Its `archivedModels` entries retain historical detail pages under `/parts/archive`, with archive reasons and current replacements. They are excluded from active catalogs, BOM fabrication sources, installed counts, figures and individual downloads. The dry bench booklet is labeled as an explicit alternative configuration.
- `bom/catalog`, `bom/assemblies` and `bom/generated/arbi-v1-hr-zagreb.json` supply systems, items, quantities, offers and the incomplete-cost summary.
- `docs/**/*.md`, `hardware/**/*.md` and `bom/README.md` supply the document index and rendered text. The text is bundled as JSON so the repository's Markdown check does not scan relocated copies.
- The camera-pod-enclosure and winch booklet packs supply the assembly GLB, STL meshes, assembly and figure manifests, and line-art figures. A pack comes from the latest `cad-vMAJOR.MINOR.PATCH` release after its checksums, release input hashes, registered outputs and embedded CAD/booklet sources match the checkout. Production rejects missing or stale releases and packs instead of falling back to old assemblies. Preview builds may use a source-checked committed pack; otherwise the affected scene is omitted until its release is ready.
- Exploded views use the booklet renderer's own exploded figures, read from `figure-manifest.json`. The camera pod uses `overview-exploded` when the pack has it, else `enclosure-exploded`. Passive and powered winches pair `cover-passive-installed`/`cover-passive-exploded` and `cover-powered-installed`/`cover-powered-exploded`, respectively. Inventories count instances within the selected configuration; BOM costs still describe the full four-winch set. Concealed fasteners that the exploded figure omits stay in place. The site authors no geometry or poses.
- Registered fabrication meshes missing from the packs, such as the dock and corner-station parts, are downloaded from the release and checked against its `SHA256SUMS.txt`. Assemblies without assembly transforms show those meshes side by side and are labelled as a parts layout, not an assembly.
- `ARBI-CAD-previews.zip` supplies a fitted line-art figure for every registered model, including CSG reference assemblies. The release renderer generates it from canonical CAD and declares the line-art style; earlier packs with shaded references are rejected. The compiler verifies the pack checksum, model identity, complete transitive source hashes and image checksum; preview builds can fall back to booklet drawings when a preview is missing or stale. Production requires a current figure for every registered model. See [preview generation](../../scripts/cad-previews/README.md). `ARBI_CAD_PREVIEW_PACK` can point to a locally generated pack for offline review.
- Each model's download link is resolved at build time. A release asset is linked with its SHA-256. Preview builds can fall back to a committed pack only after checking its source hashes, pinned to the site source commit. Archived packs are listed separately and never offered as current fabrication downloads.

The build needs no secrets. It reads the public GitHub release; set `ARBI_OFFLINE=1` for an explicit local preview of archival committed snapshots, or `ARBI_CAD_RELEASE=cad-v0.1.0` to pin a source-matched release. Production (`VERCEL_ENV=production`) rejects offline mode and requires a complete release; previews omit stale scenes and links. Turbo caching is disabled for this build because its output depends on the latest release. three.js, Tailwind CSS, marked and the fonts are bundled at build time; the site loads nothing from CDNs.

Compiler tests use `ARBI_DATA_DIR` to write to a temporary output directory
without replacing the running site's `public/data`.

Local reviews before a CAD release may set `ARBI_CAMERA_POD_PACK`,
`ARBI_WINCH_PACK`, `ARBI_CORNER_SUPPORT_PACK` and `ARBI_DOCK_PACK` to checked
assembly ZIPs alongside `ARBI_CAD_PREVIEW_PACK`. Each assembly pack must still
match its current CAD and renderer sources. Production rejects these overrides.

Every catalog item, including optional, planned and unallocated items, has a
stable `/parts/<bom-part-id>` page and reciprocal `/bom/<bom-part-id>` link.
Individual component model pages remain available. When a BOM ID also names an
assembly reference (for example `winch-drum`), the Parts page describes the BOM
kit and links its individual components. Required quantities come from the BOM;
the displayed geometry never substitutes for the assembly quantity record.

Purchased parts and items without fabrication sources have approximate
`visualization` models in the canonical CAD registry. Parts and BOM pages expose
their dimension basis and explicit rework requirements. Visualizations cannot
be used as fabrication sources or added to installed assembly counts by a parts
lineup. The CAD preview pack includes their STL meshes with checksums and full
source hashes, so local preview and production consume the same verified geometry.

## Deployment

The Vercel project is `arbi` in the Gredice team. It uses root directory `apps/arbi-docs`, Node.js 24, `ENABLE_EXPERIMENTAL_COREPACK=1`, and the custom domain `arbi.gredice.com`. It is connected to `gredice/arbi`: pushes to `main` deploy production and pull requests get previews. When the CAD release workflow publishes Latest, it requests a production rebuild through the project's `cad-release` deploy hook. `ARBI_SITE_DEPLOY_HOOK` is required: a missing hook or failed request fails the workflow, as does failure to observe the current release (or a subsequent one) on the public site within ten minutes. Rerunning the workflow reuses the immutable release and retries the refresh. A Git-triggered production build that runs before its new CAD release is available fails; Vercel retains the last successful deployment until the release-triggered rebuild passes. Documentation/BOM-only merges can reuse a release whose CAD/booklet input hashes still match.

To deploy a specific commit from the CLI, link a clean export of it to the `arbi` project first (`vercel link --scope gredice --project arbi`), then:

```bash
git archive --format=tar HEAD | tar -x -C /path/to/empty-dir
vercel deploy /path/to/empty-dir --prod --scope gredice \
  --build-env ARBI_SOURCE_COMMIT="$(git rev-parse HEAD)" --build-env ARBI_SOURCE_DATE="$(git log -1 --format=%cs)"
```

## Known gaps before the production site

- A failed CAD release or site refresh retains the last successful production site; fix or rerun the failing workflow. New geometry cannot appear until CAD export and booklet checks pass. Historical committed snapshots are explicitly archived.
- Camera pod, winch, pulley head and dock use source-checked booklet poses. The cabinet and mounted corner reference export explicit inspection scenes from canonical CAD; undeclared assemblies use a parts lineup.
- The corner root shows an ordinary winch and proposed pulley head on one round post. Its wavy break omits middle length and the mounting heights are schematic. Pulley-head and ordinary/powered winch inspection views remain separate below it.
- System BOMs expand print recipes into individual quantities and material estimates. CAD file counts include references, alternatives and coupons; BOM counts include kits. Required sets with unselected sourcing retain unresolved prices.
- Renders and CAD checks are not physical evidence. Every model is still `concept-unvalidated`.

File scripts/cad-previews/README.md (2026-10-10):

# Registered CAD previews

Generate one 480 × 360 PNG for every model in
[the registry](../../hardware/models.json). Every model uses opaque white
faces with visible feature edges and silhouettes, fitted to its own frame.
CSG references are meshed temporarily by additive component for the same line-art renderer; those
inspection meshes are deleted after rendering unless a reference explicitly
declares an assembly inspection scene. References retain their released CSG format and
engineering evidence status.

```bash
pnpm cad:check -- --require-openscad --jobs 4 --output-dir /tmp/arbi-cad
python -m pip install -r scripts/cad-previews/requirements.txt
python -m unittest discover -s scripts/cad-previews -p 'test_*.py'
python scripts/cad-previews/build.py --jobs 4 --cad-dir /tmp/arbi-cad --output /tmp/arbi-previews
```

OpenSCAD must match the registry's pinned version. CI uses VTK's EGL backend with
`VTK_DEFAULT_OPENGL_WINDOW=vtkEGLRenderWindow` and software Mesa; the same VTK
renderer also runs on macOS. Generation fails on missing exports, empty meshes,
missing or blank images, and incorrect image dimensions.

The output is `ARBI-CAD-previews.zip`, containing PNGs and `manifest.json` under
`ARBI-CAD-previews/`. The manifest declares `cad-line-art-v2`, so earlier packs
containing shaded references cannot be reused. Each entry records the model ID, revision, output name,
entrypoint, every transitively included source hash, and the image SHA-256.
The CAD release publishes the pack with its checksum. Generated figures and
temporary meshes stay outside Git.

For `visualization` models, the pack also includes the registered STL under
`meshes/`, with its path and SHA-256 in the same source-checked manifest entry.
The site uses these approximate meshes for BOM item detail pages. They remain
illustrative models with explicit assumptions and rework requirements; including
them in the pack does not make them fabrication sources.

An explicit `ARBI_ASSEMBLY_SCENE` declaration in a reference source enables
selectable assembly inspection assets, currently used by the
[control cabinet](../../hardware/assemblies/control-cabinet/README.md). The same
OpenSCAD file emits component identity/BOM ownership, colors and exploded
offsets with `emit_scene=true`, and exports each component with `scene_part=N`.
The builder stores these STL meshes separately under `assemblies/` with
checksums, covered by the reference's complete source hashes. The site accepts
the scene only when every constituent mesh is intact and registered component
ownership matches the catalog. These assets never populate the fabrication or
individual downloadable-mesh inventory. Other reference inspection meshes
remain temporary and excluded.

Reference meshing keeps subtraction, intersections and hulls intact and preserves
each component's world transforms. Components are drawn together with depth
occlusion, without an expensive assembly-wide boolean union. A temporary cache
shares identical component meshes across references; only explicitly declared
assembly inspection assets are included in the pack.
Unique components are exported with a bounded pool of OpenSCAD processes before
VTK draws figures serially. The default worker count is the available CPU count
capped at four; `--jobs N` overrides this, and `--jobs 1` runs serially. Every
reference export has a 300-second timeout to allow the large winch boolean
components to complete on shared CI CPUs; explicit assembly inspection exports
retain their 120-second timeout. Both reject compiler failures, warnings/errors
and missing or empty meshes. A failure cancels queued work and waits for active
processes before removing temporary files or returning; no pack is published.

The [public site compiler](../../apps/arbi-docs/scripts/compile-data.mjs) verifies
the release checksum and accepts each figure only when its registry identity,
complete source dependency closure, and image checksum match current sources.
Missing or outdated preview packs fall back to existing booklet drawings.
To review a new pack locally before publishing it:

```bash
ARBI_CAD_PREVIEW_PACK=/tmp/arbi-previews/ARBI-CAD-previews.zip pnpm --filter @arbi/docs dev
```

Renders establish nominal source geometry only; physical acceptance remains
separate.

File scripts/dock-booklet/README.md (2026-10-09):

# Dock booklet builder

Build the DOCK-IF-01 supported-dummy bench kit from canonical OpenSCAD sources.
Use OpenSCAD 2021.01, Python 3.12 and `../winch-booklet/requirements.txt`.

```bash
python scripts/dock-booklet/build.py --output hardware/generated/dock-booklet
python scripts/check-booklet.py hardware/generated/dock-booklet --variant dock
```

The ignored output contains a nine-page actual-mesh assembly PDF and paired ZIP
with print-oriented STLs, installed-coordinate meshes, contextual pod/post/line
meshes, canonical sources, figures and hash manifests. `kit.json` supplies per-kit
print quantities and `hardware.json` the nominal bought inventory; the committed
BOM remains authoritative. The builder checks the two inventories against the BOM.

Checks cover connected watertight parts, rigid print poses and nominal bed bounds,
part/post/current-pod interference, a synthetic vertical line pose, sampled fork
travel and supported stud release. Independent controls reproduce blocked descent
with a closed fork and a line collision in an uncut guide. These establish neither
continuous flight clearance nor material, load, weather, actuator or physical
acceptance. See [dock acceptance](../../docs/assemblies/dock/acceptance-record.md).

CI builds and checks this package; the versioned CAD release publishes the PDF and
ZIP. Sources are committed; generated meshes, figures and PDF are artifacts.

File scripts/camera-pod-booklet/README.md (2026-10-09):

# Camera pod STL assembly booklet

Build the actual registered printed mounts, simplified purchased hardware, collision-checked assembly, illustrated A4 booklet, and distributable pack.

The bench exporter explicitly selects the shared active models plus the six archived models marked `alternativeConfiguration: camera-pod-bench`. This is an alternative bench kit, excluded from current pod BOM and individual model downloads. The enclosure variant substitutes the integrated deck, white optical hood, rain hood and black tray, and uses a one-piece outer head with a separate compact carrier, integrated cradle and pivot support. Its tilt servo is horizontal and 2 mm inboard; the camera axis is Y=3, Z=-45, 14 mm higher than the dry arrangement. The head/carrier turn together in pan. The separate camera cowl and four secondary nuts are omitted; the camera uses four M2 × 12 screws, four primary nuts and eight washers. The compact kit installs 16 prints from 12 model types and exports 44 meshes: 13 fabrication models including the optional coupon, 30 nominal hardware references and one routing proxy. The fixed fairing, servo boot and rear cowl are archived and excluded from both exports. Dry cradle and pivot support are retained only in the explicit bench alternative. Its Pi moves inward, the converter turns 90 degrees, and the capacitor sits alongside it. The separate historical `camera-pod-*` and `camera-gimbal-*` concept kit is archived and excluded from current exports. Model reuse also checks the shared libraries that define the spider and integrated gimbal.

```bash
python3 -m pip install -r scripts/winch-booklet/requirements.txt
python3 scripts/camera-pod-booklet/build.py --output hardware/generated/camera-pod-booklet
python3 scripts/camera-pod-booklet/build.py --enclosure --output hardware/generated/camera-pod-compact-gimbal
```

OpenSCAD must be the registry-pinned 2021.01. VTK 9.5.2 is pinned for rendering. On macOS, its Cocoa backend needs access to a working OpenGL context; a restricted agent may need to run rendering outside the sandbox. The wrapper reuses rendering/layout helper functions from the winch generator and takes a source snapshot. It does not infer fabrication dimensions from illustrations.

`--reuse-models` requires the same variant, matching CAD input hashes and STL hashes, then reruns assembly/service checks and rendering. `--checks-only` exports and checks without rendering a PDF or creating a ZIP. `--publish` copies the PDF and ZIP into the camera-pod documentation folder when a repository snapshot has been requested.

The assembly definition is `integration.py`. `check_integration.py` checks nominal rigid interference through 555 pan/tilt poses and overtravel stops. `check_service.py` checks assembly paths, staged tool access, the nominal viewing volume, and a deliberately incorrect proud-head regression control. The enclosure adds a 111-pose rigid fixed-power-route proxy and an intentionally misplaced central-drop regression control. The compact-gimbal build passes 30 service paths, 22 tool envelopes, six port/drain envelopes, 15 optical poses and the 111-pose route check, with both negative controls detected. The paths include complete M2 camera bolts and Ø5 mm front washers through optical hood tunnels, head nut/washer preloading, top-down head bolts, lateral pivot-support fitting and removal of the head, camera and carrier. Regenerate these outcomes whenever the selected revisions change; the earlier cowl-based service report does not apply. Both checkers must pass before the PDF is built. For cradle r0.1.1, `check_cradle.py` also verifies the original bounding box, open interfaces and at least 30 mm² through three horn/frame sections; a deliberately thin joint must fail. Its report is included in the enclosure evidence. Print this cradle with the outer horn face on the bed (−90° about Y, then place on bed); inspect remaining bridges and use local supports where needed. See the [cradle record](../../hardware/assemblies/camera-pod/camera-pod-camera-cradle-check.md).

Populate the carrier outside the body and fit the pan OEM centre screw before installing the camera. At the bench, fasten the stock tilt horn and retainer to the separate cradle before engaging the mounted tilt servo; its case blocks the rear retainer driver afterward. Seat the cradle, secure the tilt OEM centre screw, then slide the opposite support inward along -X from 12 mm to its right. Secure the support and existing M3 pivot before fitting the camera; the previous upward support path collides with this geometry. Slide each body M2 nut and lower washer 11 mm outward from its inward-facing opening, raise the body around the complete neutral carrier, and install four M2 x 10 bolts from above before fitting the upper tray and electronics. For service, support the spider and fixed pan mount with a bench fixture, release the harness and remove the upper stack. At neutral, remove the four upper head bolts/washers and lower the body with its captured lower hardware. With the body off, remove the four rear camera nuts/back washers, then lower the camera/optical hood and front fasteners. There is no separate cowl-removal stage. The open cradle then admits the OEM pan-centre driver and screw removal before lowering the supported carrier from the fixed servo. The report records the parts removed at each stage and checks 80 mm head-bolt and 65 mm pan-centre driver shafts; handles and wrench turning remain unmodeled.

The 6 mm fixed-power proxy runs from `[10,40,24]` down to `[10,40,1]`, outward above the head to `[10,60,1]`, then down to `[10,60,-61]` and out to `[10,70,-61]`. The nominal route clears the upper tray skirt and moving head in the current sampled checks; actual bend radius, sleeves and flexible loops require physical inspection.

Servo and power-module geometry remain provisional. The current 16-print solid-volume PETG estimate is 253.927 g at 1.27 g/cm³, excluding electronics and hardware. Inspect the slicer output and weigh the complete assembly against the original flying mass ceiling; this estimate is not sliced or measured mass. Omitting the cowl requires new physical rain checks around the camera connector and CSI loops. The booklet is a supported bench assembly guide. Ingress, temperature, flexible-cable movement and suspended operation remain unverified.

Each build records its variant in `configuration.json`, resolves STL revision filenames from the registry, and includes source/STL hashes, mesh/assembly/figure manifests and geometry/service results. Enclosure artifacts use the `ARBI-camera-pod-enclosure` prefix; `--publish` stores separate enclosure snapshots and `camera-pod-enclosure-check.json` alongside the refreshed bench publication. Earlier r0.1.0 bench evidence is retained in dated files and its revision 2 pack remains in Git history. The current palette is documented in [industrial design conventions](../../docs/project/industrial-design.md).

## CI and drawing style

Bench revision 4 and enclosure revision 5 use the shared white-face line-art
renderer. Visible silhouettes and feature edges make dark cores, small brackets
and hardware readable; the GLB and manifests keep the product palette. Each
configuration has its own header and page total (14 bench, 16 enclosure).

The `overview-exploded` figure separates the whole assembly layer by layer along the spider axis. The compact outer head and its fasteners have a separate layer from the internal carrier; its opposite support separates laterally to the right. The dry variant retains its existing exploded layout. The overview is not placed in the PDF. Its transforms in `figure-manifest.json` are the exploded pose used by the public site (`apps/arbi-docs`).

The enclosure also includes product-color views rendered by `render_preview.py`
from the same CAD meshes. `product-hero` and `product-front` use tilt 70 degrees
to show the optical face. `product-eye-aligned` uses the same pose and looks
along the actual lens axis, retaining the full assembly and its possible
occlusions. `product-neutral`, `assembled-neutral` and the GLB retain tilt 0,
with the camera pointing down; the booklet's line-art `assembled-covered`
remains at tilt 55. `product-electronics` shows the roof removed. `product-underside` and `product-bottom` show the operated underside at neutral; `product-underside-pan90` shows its seam at pan 90 degrees. The tray/head neck check measures actual horizontal STL segments through their 2 mm overlap, bounds clearance for every pan angle, and detects an oversized-neck collision control.
`preview-manifest.json` records each product view's pan/tilt angles, viewing
direction and part transforms separately from the booklet's grayscale
`figure-manifest.json`.

[Booklet jobs in CI](../../.github/workflows/ci.yml) build and check affected camera pod
variants the winch and corner support from fresh CAD exports on relevant pull requests, and all
four on release runs or manual dispatches. PR PDFs/ZIPs are downloadable for 14 days. The
[CAD release workflow](../../.github/workflows/ci.yml) publishes the
four PDF/ZIP pairs with the same commit's STLs and checksums on `main`. CI does
not use `--publish` or rewrite checked-in snapshots/evidence.

```sh
python3 scripts/check-booklet.py hardware/generated/camera-pod-booklet --variant bench
python3 scripts/check-booklet.py hardware/generated/camera-pod-compact-gimbal --variant enclosure
```

These checks verify pagination, configuration/revision labels, registry filenames,
hashes, non-empty figures and paired PDF/ZIP contents. Visually inspect every PDF
page before updating repository snapshots with `--publish`.

See [mount interfaces and quantities](../../hardware/assemblies/camera-pod/camera-pod-mounts.md) and [geometry evidence](../../hardware/assemblies/camera-pod/camera-pod-geometry-check.md).

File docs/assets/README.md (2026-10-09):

# Project imagery

## Official brand assets

The owner selected **Garden Focus** as ARBI's official logo on 7 October 2026.
The [brand guide](../project/brand-identity.md) defines the identity, available
files and usage rules. The assets live in [brand](brand):

- [Primary logo](brand/arbi-logo.png): horizontal logo on warm white, used by the repository and documentation headers.
- [Transparent logo](brand/arbi-logo-transparent.png): horizontal logo for light backgrounds.
- [Transparent emblem](brand/arbi-mark-transparent.png): standalone leaf/lens and viewfinder mark.
- [Selected artwork](brand/garden-focus-selection.png): unchanged owner-selected concept reference.
- [Generation record](brand/generation.json): built-in image tool, date, input relationships and exact prompts for the selection and derived PNG assets.

## Concept imagery

- `camera-pod-concept.png`: owner-supplied integrated camera-pod concept, selected on 7 October 2026. The appearance is recorded in the [design conventions](../project/industrial-design.md).
- `arbi-cover.png`: scenic concept imagery updated with the built-in image-generation tool on 7 October 2026, using the preceding repository cover as the edit target and the selected camera pod as the appearance reference. It is not CAD, an installation photo or dimensional engineering evidence.

## Scenic-cover edit prompt

This is the exact historical prompt used on 7 October 2026; its wording predates the camera-pod naming migration.

Use case: precise-object-edit. Asset type: ARBI public engineering repository scenic hero. Image 1 is the edit target; image 2 is the accepted payload appearance reference only. Preserve image 1's panoramic raised-bed garden, sunset lighting, timber posts, four taut overhead positioning cables, landscape and lower-left typography. Replace only the small suspended camera payload in the upper center with the compact integrated payload from image 2: one rounded warm-white upper enclosure, charcoal black structural core and capsule-ended X spider with four cable attachment points, hanging dark open two-axis gimbal and a small white camera bezel. Match the original object's scale, perspective, attachment height and sunlight. Keep the four cables actually connected to the four spider arms; no propellers, no extra cables, no batteries. Preserve text exactly: 'ARBI' and 'Automatic Raised Bed Imaging system'. This is scenic concept imagery, not manufacturing CAD. Do not change other scene objects or add text. Return the same wide aspect ratio as image 1.

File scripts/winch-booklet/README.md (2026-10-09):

# Winch booklet generator

This workflow exports current ARBI winch models, makes bought-part reference
STLs, renders assembly views from the meshes and builds the A4 PDF and portable
STL/source pack. The source models in `hardware/` remain canonical.

Install OpenSCAD **2021.01** and Python 3.12 or compatible. Install the Python
dependencies from `requirements.txt` in a virtual environment. VTK 9.5.2 needs
a working OpenGL/EGL/OSMesa backend for rendering; the documented build used EGL.
Run from the repository root:

```sh
python3 -m pip install -r scripts/winch-booklet/requirements.txt
python3 scripts/winch-booklet/build.py
```

Outputs go to ignored `hardware/generated/booklet/`. The build copies the current
winch CAD, scripts and fonts into a portable source snapshot, validates 86 STLs,
writes hashes and part transforms, renders the figures and generates the PDF/ZIP.
Use `--output PATH` for another build location. `--publish` updates the checked-in
PDF and ZIP under `docs/assemblies/winch/booklet/`.

After text or camera edits, `--reuse-models` skips CAD exports only if the source
input hashes and all STL hashes still match. CAD changes require a full rebuild.
Rendering and PDF generation always rerun. Old model revisions are removed on a
full export. The snapshot is identified by content hashes; its recorded Git base
commit can precede edits in the working tree. This avoids falsely claiming that
a PDF generated before its own commit came from an unchanged earlier revision.

## CI and drawing style

The shared renderer makes white-face line drawings with dark silhouettes and
visible feature edges. Opaque faces hide rear edges and omit the STL triangle
grid. Product colors remain in the figure/assembly manifests and camera pod GLB.

In exploded cover views, the disconnected stationary loom references move with
the lower fascia that carries their exit holes. This preserves cable-to-port
alignment throughout the website's exploded-view animation. Their inner ends
extend under the rear of the nominal motor body in both poses; it illustrates
disassembly, not a flexible-cable deformation or service procedure.

Bought meshes record their owning `bomPartId` in the figure manifest. Motor,
drum joining/clamp, mount and cover hardware open their existing BOM pages in
the website; repeated fastener meshes retain the owner of each installed stack.

[Booklet jobs in CI](../../.github/workflows/ci.yml) build affected winch, dry camera pod
and enclosed camera pod variants in separate jobs with Python 3.12, OpenSCAD 2021.01 and VTK
9.5.2 on software EGL. Relevant pull requests get downloadable PDF/ZIP artifacts
for 14 days. The required CI result includes booklet checks. A manual workflow
dispatch rebuilds all four variants, including the [corner support package](../corner-support/README.md), from the selected branch.

On `main`, [the release job in CI](../../.github/workflows/ci.yml) reuses all
four validated booklets and adds them to the `cad-v<MAJOR.MINOR.PATCH>` release alongside the
registered STL/CSG files and checksums. CI uses fresh exports, with neither
`--reuse-models` nor `--publish`; it does not commit generated files back to Git.
Checked-in PDFs/ZIPs are dated snapshots; releases contain commit-matched builds.

Validate a local build with:

```sh
python3 scripts/check-booklet.py hardware/generated/booklet --variant winch
```

The check verifies A4 page totals, headers, revisions, source/STL hashes,
registry filenames, non-empty line-art figures and matching PDF/ZIP contents.
It also checks both variants' cable meshes against the motor and port-bearing fascia at
the installed, exploded and three intermediate animation poses.
Render every PDF page for visual review before updating a checked-in snapshot.

## Editing

| File | Responsibility |
| --- | --- |
| `build.py` | Snapshot, dependency order, packaging and optional publication |
| `export_arbi.py` | Registered winch fabrication exports and mesh manifests |
| `reference-parts.scad` | Nominal purchased-part geometry |
| `export_reference.py` | Reference STLs, including base plates from canonical CAD |
| `render_figures.py` | Assembly transforms, cameras and STL render manifest |
| `build_booklet.py` | Booklet text, vector labels and A4 page layout |
| `pack-README.md` | User-facing instructions included in the ZIP |

Resolve fabrication filenames from the model registry. Keep corresponding BOM
revisions current. Never make a picture fit by changing the rendered custom part
independently of its CAD. Hardware details without supplier confirmation remain
labelled references. The motor screw illustration is a representative M4 through
stack; actual screw selection depends on the received flange.

## Verification and publication

Run the mount mesh checker and the CAD/BOM/docs checks described by the repository.
Render every PDF page with Poppler and inspect it after layout changes. Verify
current revision filenames and no old cover in the ZIP. Review affected views
with actual motor and cover attachment hardware present. The booklet build is
not a physical fit or load validation.

The [published booklet directory](../../docs/assemblies/winch/booklet/README.md)
records the owner's request to commit the downloadable artifact snapshot. Other
working STL exports and individual render PNGs remain ignored. The reusable
skill is maintained under `.agents/skills/create-assembly-booklets/`.

Revision 7 retains the distinct powered index-3 transition panel from revision 6 and adds line-art illustrations. The full-cover kit includes
main panels, payout shutters, clips, fixed-loom anchor,
covered-base drilling references and nominal line/loom references. The PDF has
18 pages; the pack contains 27 fabrication and 35 reference meshes. Run
`python scripts/check-winch-cover-meshes.py hardware/generated/booklet/models/arbi`
for the full-cover nominal checks, as well as the existing mount checker.

Revision 8 adds concealed fasteners: 34 fabrication + 35 reference meshes, 19 pages. Main panels/clips r0.2.0; fascia, rear shields and optional bench blank r0.1.0. Check nominal geometry with the full-cover checker; inspect key fit physically before service.

Revision 9 adds bottom stationary-loom ports, round-timber saddles and concealed
rear nuts: 42 fabrication + 44 reference meshes, 20 pages. Metal saddle STLs are
machining references and must not be printed. The build runs both the full-cover
and round-pole nominal mesh checks; 100/120/140 mm pole cases retain unvalidated
physical fit, structural capacity and cap/guide retention.

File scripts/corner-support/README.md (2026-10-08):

# Printed corner support package builder

Use OpenSCAD 2021.01 and the existing
[booklet Python dependencies](../winch-booklet/requirements.txt).

```sh
python3 scripts/corner-support/build.py
```

The fresh temporary build exports the six registered printed fabrication models,
nominal bought references and deliberate print poses. It checks round 100/120/140
mm, passive/powered line assumptions and square-100; bolt engagement, alignment,
socket access, installed clearance and sampled cover-removal paths. It renders
actual meshes with the existing winch line-art renderer and writes an eight-page
A4 PDF, GLB, hash reports and verified portable source/STL ZIP. Working outputs
go to ignored `hardware/generated/corner-support`; `--output` overrides it.

The default printed head replaces the angle, machined saddles and stacked backing
plates. It retains ordinary metal through-bolts, washers, locking nuts,
cross-bolts and the received pulley/pin. Historical metal geometry remains in
the source snapshot for context, but its fabricated meshes are absent from the
new installed scene. Never combine study variants in one installation.

## Frames and printing

`models/arbi` files use the installed frame in millimetres. The rear-pad STL is
centred at Z=0; two installed instances sit at Z=45/155. The template is already
flat. `models/print` files rotate each real fabrication mesh into its documented
print pose, then translate its XY minimum to zero. The geometry report records
the complete rigid installed-to-print matrix and read-back mesh bounds. The GLB
uses metres and applies the real installed transforms.

Each part is checked separately against a nominal 256 × 256 × 256 mm printer
envelope, with a 5 mm edge reserve in XY: maximum footprint 246 × 246 mm. This
bounding-box check is not slicing approval and does not reserve brim, supports,
purge lines or machine-specific excluded areas. The carrier web faces lie on
the bed; the central lug and horizontal holes need reviewed local supports.
See the [design package](../../docs/assemblies/corner-station/design-package.md)
for process and load qualification. No numerical slicing settings or strength
rating follows from a watertight mesh or a nominal bed fit.

The builder exports from canonical SCAD into an empty temporary directory. It
reads the written STLs back and checks watertightness, winding, positive volume,
single connected bodies, current registry filenames, print transforms and bed
bounds. It compares every installed custom part instance against references and
other custom parts with only zero-volume mating contact permitted. Portable
canonical sources are under `source/repository`; rebuild from an ARBI checkout
with the pinned tooling. Stale output-folder files never enter the ZIP.

The provisional block uses the frictionless equal-leg-tension 90-degree pose:
-45° about its Y pin, with a 40 mm pin-to-sheave distance. An independent
moment calculation rejects the vertical block pose, and the actual block mesh
is compared with the transformed vertical reference. The new pin X offset
preserves the canonical winch tangent; arbitrary span azimuth and received
articulation remain unqualified. One-mm³ lug/web probes reject accidental
extended M12/pin cutters. Regression controls also reject an unrelieved cover
fascia and the old front-cover X/Y removal. The checked service is front cover
190 mm down then 100 mm sideways, and rear cover 80 mm backward.

Render every PDF page with `pdftoppm` and inspect it after layout changes. These
checks establish nominal geometry only. Received BA01090 pin/groove/retention,
guy attachment, print process, long-term creep, timber, soil, structural load
capacity and installed operation require separate acceptance.

Validate the final archive and current source hashes with:

```sh
python3 scripts/check-booklet.py hardware/generated/corner-support --variant corner
```

CI builds this fourth booklet variant and includes its PDF/ZIP in CAD releases.
The public site consumes the checked installed/exploded mesh poses. For local
site review, set `ARBI_OFFLINE=1` and `ARBI_CORNER_SUPPORT_PACK` to the ZIP path.
Production accepts only the verified release asset, with current source hashes.

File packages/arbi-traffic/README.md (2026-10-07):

# @arbi/traffic

Implemented shared Node 24 transfer taps, bounded SQLite raw-counter/attempt spool, Linux sysfs collector and optional bounded router snapshot adapter for [#26](https://github.com/gredice/arbi/issues/26). The [edge executable](../../apps/arbi-edge-controller/README.md) and its simulated pod consume the application adapter. [Metering semantics](../../docs/software/device-traffic-metering.md) and [host evidence](../../docs/evidence/device-traffic-metering.md) define coverage and remaining gates.

Build with `pnpm --filter @arbi/traffic build`; portable fixtures with `pnpm --filter @arbi/traffic test`; native Linux loopback comparison with `pnpm --filter @arbi/traffic test:linux` after build. The last command fails on other platforms. Node SQLite is a runtime requirement. Internal dependencies use `workspace:*`; no new pod application or provider dependency exists.

`ApplicationMeter.upload` and `download` wrap real chunk submission/receipt. `submit` observes a callback-based socket submission; `observe` is a best-effort received-buffer tap. Each attempt has its own ID, category, scope, raw timestamps and outcome. Every retry is counted again with optional `retryOf`; it stays in the original category with retries included. Neither a local write callback nor received bytes proves remote application acknowledgement, successful object storage, watching, installation or physical behavior.

`TrafficSpool` takes an explicit file, realm/site/mode/device binding and four capacity bounds. `pending` returns up to 64 terminal raw records and hashes; a prefix can be removed only through `acknowledge({id,contentHash,durable:true})`. The caller must obtain a real durable sink receipt; this library does not fabricate one or implement cloud ingestion. Active attempts remain on disk and become partial `crashed` records on the next single-writer startup. Stop local work before attempting accounting cleanup. Strict upload/download wrappers surface storage failures; socket taps contain those failures and preserve explicit degraded status.

`LinuxInterfaceCollector` reads one explicitly configured interface and a caller-maintained deployment epoch. `RouterCollector` accepts one source-specific report callback, explicit coverage/directions/collection point, a 1–10,000 ms timeout and at most 4 KiB JSON snapshots. The callback must bound its own HTTP response and honor `AbortSignal`; an ignored abort quarantines that outstanding callback so later polls cannot accumulate requests. No vendor protocol, default SIM, endpoint, credential or tariff is assumed. `parseRouterSnapshot` validates the full report shape and exact unsigned values. Configurations and reports belong in private deployment storage.

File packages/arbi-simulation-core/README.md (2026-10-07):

# @arbi/simulation-core

Implemented deterministic offline scenario runner, affine trajectory and Euclidean cable references, uint32 seeded disturbances, normalized traces and adapter seams. It consumes [@arbi/protocol](../arbi-protocol/README.md) via `workspace:*`. No dependency on the dashboard, cloud, enrollment, devices or providers exists.

From the repository root, after installing pinned dependencies:

```sh
pnpm scenario:check
pnpm --filter @arbi/simulation-core scenario
pnpm --filter @arbi/simulation-core scenario ../arbi-protocol/fixtures/scenarios/1.0/disconnected-cloud.json
node packages/arbi-simulation-core/dist/runner.js packages/arbi-protocol/fixtures/scenarios/1.0/healthy.json packages/arbi-protocol --trace
python3 -I -B packages/arbi-protocol/conformance/scenario.py packages/arbi-protocol/fixtures/scenarios/1.0/healthy.json packages/arbi-protocol --trace
```

`scenario:check` builds both packages before testing. The CLI defaults to the healthy fixture, validates declared golden results and emits a JSON report; `--trace` adds every normalized row. Paths passed through a package script are relative to that package. Validation failures exit 2 with a bounded named error and no success output. Library exports include `runScenario`, `checkScenarioExpected`, `referenceTrajectory`, `seededRandom`, `q6` and the implemented `simulatedAdapters` factory.

The [scenario specification and evidence](../../docs/software/scenarios.md) define ordering, numerical normalization, consumer independence, model limitations and physical gates. The default adapters expose simulated estimates/commanded gimbal targets and unavailable physical feedback. Future device adapters can implement these method boundaries in a separately gated local runtime; this runner requires `executionMode: simulation`. An adapter mode tag is a caller contract, not a security boundary against arbitrary untrusted JavaScript. No hardware implementation or endpoint is supplied.

## Bounded plant model

The additive `arbi.plant/1.0` model implements synchronized cable/drum references, configurable driver/local-input/power/gimbal/camera adapters, seeded delay/noise and imaging/return sequences. [Model contracts, timing, evidence and limits](../../docs/software/bounded-plant-model.md) distinguish estimates and virtual sensors from physical measurements. `runPlant`, `validatePlant`, `boundedPlantAdapters`, `cableLengths`, `drumMapping` and the portable module interfaces are exported. Scenario 1.0 behavior remains unchanged.

```sh
pnpm scenario:check
pnpm --filter @arbi/simulation-core plant
node packages/arbi-simulation-core/dist/plant-runner.js packages/arbi-simulation-core/fixtures/plant/1.0/nominal.json packages/arbi-protocol --trace
python3 -I -B packages/arbi-simulation-core/conformance/plant.py packages/arbi-simulation-core/fixtures/plant/1.0/nominal.json packages/arbi-protocol --trace
```

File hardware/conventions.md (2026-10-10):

# OpenSCAD conventions

## Source of truth

- `.scad` files are canonical custom-part geometry.
- `hardware/models.json` is the release-entrypoint and design-revision registry.
- `hardware/models.schema.json` is the machine-validated registry contract; the registry pins the exact supported OpenSCAD version.
- Exported meshes are derived artifacts. Publish them from tagged source through CI or a GitHub release.
- A BOM or assembly revision that depends on fit must name the compatible model revision.

## Appearance

Follow the [industrial design conventions](../docs/project/industrial-design.md) for shells, cores, optical surrounds and previews. Colors communicate part roles; they do not establish material or validation status.

## Units and coordinates

- All dimensions are millimetres.
- Use a right-handed coordinate system.
- Model a printable part in its intended default export orientation when practical.
- State any assembly coordinate frame, datum, mating surface, axis, and required transformation in the owning README.
- Use descriptive parameter names with a unit suffix when the unit is not obvious.

## Parametric design

- Expose dimensions that govern interfaces, tolerances, material thickness, fastener clearance, or printer adaptation.
- Validate parameters with `assert()` so impossible combinations fail visibly.
- Reuse modules from `hardware/lib/arbi.scad` before copying geometry.
- Pass facet counts explicitly for curved release geometry; do not rely on a developer's global `$fn`.
- Use a small named epsilon for subtractive geometry rather than unexplained offsets.
- Avoid absolute include paths, environment-specific fonts, or external assets that are not committed.

## BOSL2 library

Use the [vendored BOSL2 v2.0.766](vendor/BOSL2/README.md) through the existing
`hardware/lib/arbi.scad` include. Its version, upstream commit, license and source
hashes are pinned in the repository and checked by `cad:check`; a user-installed
copy is not a build input. Portable source packs contain the same pinned files.

Keep helper interfaces and assembly datums explicit. BOSL2's `cuboid()` and
`cyl()` center by default, and rounding all edges can change flat mating faces.
Preserve release facet counts, printer clearances and named epsilons. Use
attachments only after defining the part's local frame and mating anchors.
Library refactors require mesh and clearance comparisons; shorter code alone is
not evidence of faster exports or physical validation.

## Revisions and status

Model revisions use semantic `major.minor.patch` form:

- patch: source correction with no intended physical-interface change;
- minor: backwards-compatible parameter or geometry addition;
- major: mating, fit, envelope, assembly, or other physical compatibility break.

Initial models use `concept-unvalidated`. Change status only with linked evidence:

- `prototype`: a specific revision has been fabricated and inspected;
- `validated`: defined acceptance checks passed under recorded conditions;
- `released`: approved for a named repository release/build configuration;
- `deprecated`: retained for reproducibility but not recommended for new builds.

Git history records development. The explicit model revision identifies a physical interface that builds and BOMs can reference.

## Tolerances and safety

- Do not bury printer clearances, press fits, bearing fits, or fastener clearances in decorative constants.
- Record material, print process, layer direction, infill/perimeters, inserts, fastener torque, and environmental assumptions in validation records rather than implying they follow from geometry.
- Printed parts that carry tension, retain a moving line, support overhead equipment, isolate conductors, or participate in docking require physical and safety review.
- OpenSCAD compilation, a visually plausible render, and a successful print do not prove load capacity, fatigue life, insulation, UV resistance, weather resistance, or safe operation.

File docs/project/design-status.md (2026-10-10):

# Design status

## Meaning of this page

This is a current evidence inventory, not a purchasing list and not a certification statement. “Baseline” means selected in the current committed design. “Unverified” means no repository evidence currently demonstrates the claim.

## Status summary

| Area | Current baseline | Evidence status |
| --- | --- | --- |
| Site | 25 current beds, 30-bed capacity, approximately 29.2 × 6.6 m anchor rectangle | Geometry recorded; actual site survey unverified |
| Corner stations | Four treated timber posts with outward guys and approximately 3 m pulley height | [Printed-head design proposal](../assemblies/corner-station/design-package.md) adds winch-aligned carrier halves, integrated post adapters, rear pads, covers and ordinary bought fasteners; print process, load/creep/weather qualification, received pin/keeper/guy fit and site/structural acceptance remain unverified. Historical metal alternatives remain separate |
| Winches | Direct-drive 3 Nm closed-loop steppers, external shaft bearings, single-layer printed drums | Selected concept; [full-cover nominal CAD/service checks](../../hardware/assemblies/winch/full-cover-check.md) added; physical fit, force, heat, weather and guarding unverified |
| Winch-owned positioning lines | Three normal Dyneema lines plus one 48 V powered hybrid line | Novel powered-line construction; fatigue, insulation, and cycle life unverified |
| Camera pod | Pi 3A+, Camera Module 3, two micro servos, 100–120 g target, 170 g ceiling | [dry bench record](../../hardware/assemblies/camera-pod/camera-pod-geometry-check.md), [earlier record](../../hardware/assemblies/camera-pod/camera-pod-geometry-check-2026-09-28.md), selected [compact gimbal inside a one-piece moving head](../../hardware/assemblies/camera-pod/camera-pod-enclosure.md), and [current reinforced-cradle CAD record](../../hardware/assemblies/camera-pod/camera-pod-camera-cradle-check.md); compact-gimbal nominal CAD checks, including the continuous underside seam, pass; 253.927 g solid-volume PETG estimate for 16 installed prints (not sliced or measured mass); moving-head torque/settling, complete flying mass, fit, rain, thermal, electrical and imaging acceptance remain unverified |
| Dock | High dock on a non-powered corner, sharing the corner-set post configuration; passive capture remains the intended operating behavior | DOCK-IF-01 r0.1.0 [supported-dummy bench kit](../assemblies/dock/assembly-guide.md) adds 11 fabrication models, a manual fork, spider bridge, split arm and roof, plus a reproducible PDF/STL pack. Nominal mesh checks cover the current pod, fasteners and sampled manual release. The pod attachment adds about 118 g of solid-volume PETG before hardware; complete mass, clamp retention, automatic capture, actuator/sensors, load/weather and all-line power-loss restraint remain unverified. The [acceptance record](../assemblies/dock/acceptance-record.md) is blank |
| Control cabinet | Protected 230 V entry, two 48 V/350 W supplies, Pico 2 W control, fused branches | Logical baseline and [proposed cabinet layout with assembled/exploded CAD](../assemblies/control-cabinet/layout-proposal.md) recorded; enclosure selection, protection coordination, earthing, thermal, and field wiring unverified |
| Motion software | Local synchronized STEP/DIR control, Euclidean cable targets, positive tension | No implementation or real-system validation recorded here |
| Imaging software | Move, stop, gimbal, settle, autofocus, capture, rectify, upload | Desired workflow; settling time and repeatability unverified |
| Safety | [Local safety authority and instrumentation requirements](../decisions/0006-local-safety-authority-and-instrumentation.md), independent limits/stopping, docking and restraint | [Interface owners and evidence gates](../system/local-safety-interface-matrix.md) recorded; circuits, measurements, power-loss restraint and qualified physical review remain unverified; safety case incomplete |
| Simulation | [Scenario 1.0](../software/scenarios.md) and [bounded plant/module references](../software/bounded-plant-model.md); future digital twin and controller-tuning environment | Deterministic TypeScript/Python host evidence recorded; physical model fidelity, runtime integration and field behavior unverified |
| Online software and deployment | [ADR-0005](../decisions/0005-software-architecture-and-deployment.md): Vercel dashboard/API, Ably notifications, external Postgres/private objects, independent local runtimes and releases | [Capability review and local recovery experiment](../evidence/software-transport-feasibility.md), [site authorization](../software/site-authorization.md), [simulation-only enrollment/transactional inventory](../software/device-enrollment.md) and [image metadata/private Blob SDK boundary with isolated HTTP/PostgreSQL evidence](../software/image-storage.md) recorded; [durable cloud jobs/exclusive leases with isolated PostgreSQL evidence](../software/command-jobs.md) recorded; [authenticated dashboard shell and explicit bounded-plant test provider](../software/dashboard-shell.md) recorded with [separate source/hosted evidence](../evidence/dashboard-shell.md); [bounded current telemetry/event history and configured assembly inventory](../software/telemetry-history.md) recorded with [isolated database/HTTP evidence](../evidence/telemetry-history.md); live provider integration, broker routing, live media, OTA recovery and physical operation unverified |
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

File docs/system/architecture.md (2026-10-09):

# System architecture

## Overview

ARBI uses four fixed winches and four positioning lines to move one lightweight camera pod above raised beds. Skycam motion provides coarse position; after motion stops, a two-axis gimbal provides fine framing. The local system captures, rectifies, caches, and uploads images requested by a schedule or user.

```mermaid
flowchart LR
    CLOUD["Gredice imaging API"] --> EDGE["Local edge service"]
    EDGE --> MCU["Pico 2 W motion controller"]
    MCU --> W["Four winch assemblies"]
    W --> L["Four positioning lines"]
    L --> POD["Camera pod"]
    EDGE <--> POD
    POD --> DOCK["High HOME dock"]
    CAB["Control cabinet"] --> MCU
    CAB --> W
    CAB -->|"48 V through hybrid line"| POD
```

## Physical architecture

### Site installation

Defines the bed footprint, anchor coordinate frame, access zones, clearances, field routing, fiducials, and as-built survey. See [site installation](../assemblies/site-installation/README.md).

### Four corner stations

Each station supports a top pulley and reacts positioning-line load through its post, guy, anchor, and soil. A winch mounts on the same pole face below the pulley. One corner also supports the dock. See [corner station](../assemblies/corner-station/README.md).
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

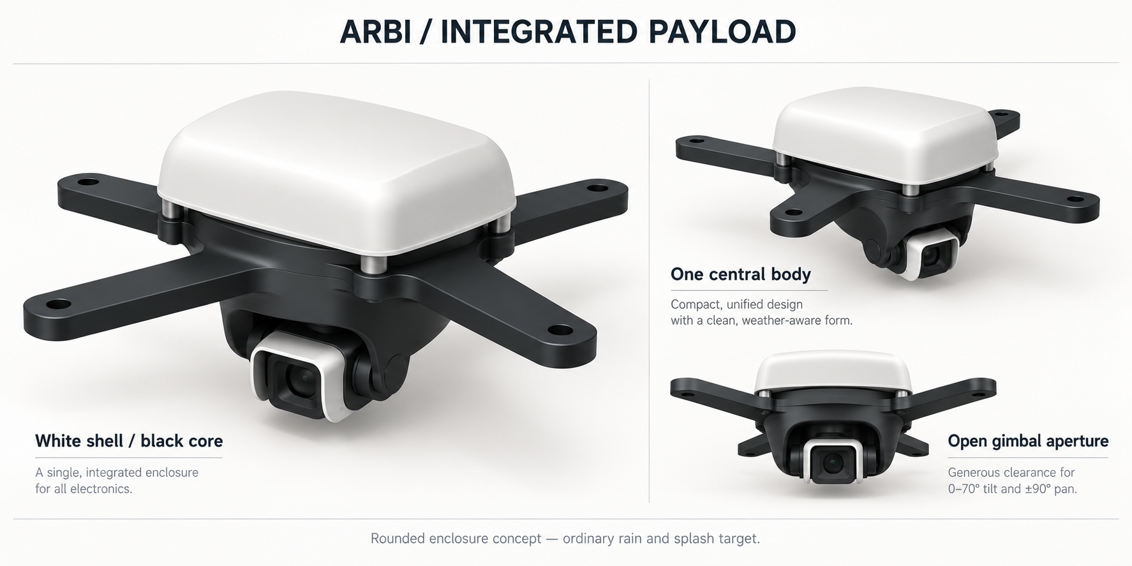
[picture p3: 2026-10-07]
docs/assets/camera-pod-concept.png

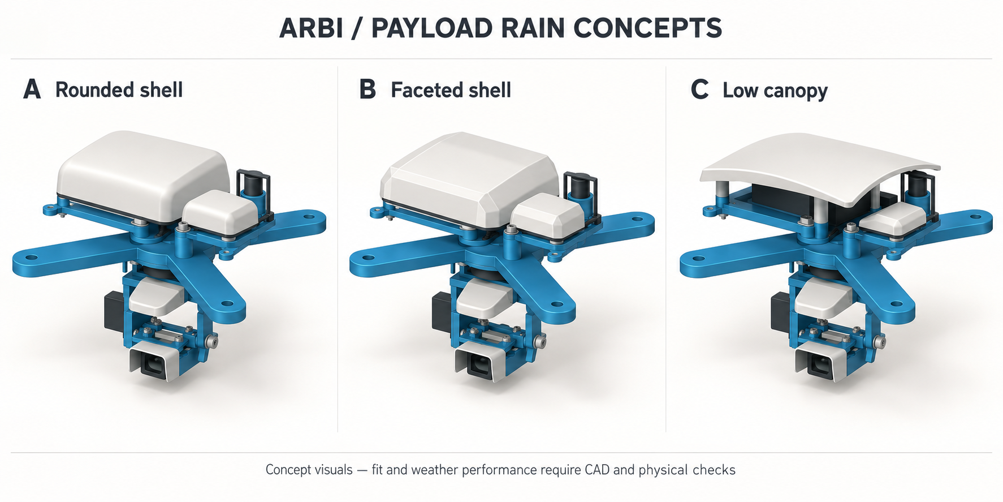
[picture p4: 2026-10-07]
docs/assemblies/camera-pod/enclosure/concepts.png

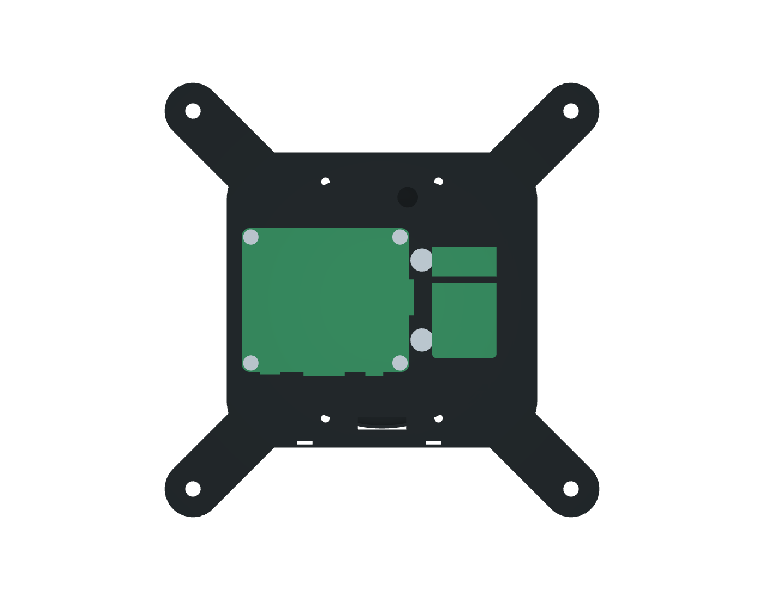
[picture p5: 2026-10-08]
docs/assemblies/camera-pod/enclosure/compact-electronics-cad.png

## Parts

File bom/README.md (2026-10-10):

# Bill of materials

ARBI keeps engineering requirements, physical ownership, supplier identity, purchasable offers, destination-specific quotes, and calculation scenarios as separate versioned JSON inputs. This avoids treating a supplier row or a component type as a physical subsystem.

## Source of truth

The files under `bom/` are the sole canonical BOM records for the project. Parts, assembly quantities, offer selections, quote observations, and calculation policy change only through reviewed Git commits. There is no external database, synchronization job, or row-mapping authority.

Supplier websites and offer URLs are procurement evidence. Dated price, availability, tax, and shipping observations live in quote snapshots. Those references support the repository records but never override them.

## Canonical inputs

- `catalog/parts.json`: stable engineering part identities and requirements. Quantities do not live here.
- `assemblies/assemblies.json`: quantities owned by actual physical assemblies.
- `assemblies/builds.json`: build definitions and assembly instances.
- `catalog/suppliers.json`: stable supplier identities and uniquely owned checkout groups for each seller, warehouse, or basket boundary.
- `catalog/customs.json`: shared destination customs policies with start/end dates, fixed charge per item type and order-value limits.
- `catalog/offers.json`: purchasable packages, bundles, URLs, qualification state, MOQ, package contents, and relevant notes.
- `catalog/fabrication.json`: print-kit quantities, source-matched CAD volumes, material densities and dated roll prices and bulk-order conditions for material consumption estimates.
- `locations/locations.json`: privacy-safe destination and tax context.
- `quotes/*.json`: immutable destination-specific price observations, currencies, exchange rates, timestamps, and checkout-group shipping evidence.
- `scenarios/scenarios.json`: pinned selection and reporting policy.
- `schemas/*.schema.json`: contributor-facing JSON Schema contracts.

Fasteners, cables, electronics, electrical parts, mechanical parts, optics, and printed or fabricated parts are disciplines or traits. They can appear inside every physical assembly; they are not top-level ownership categories.

## Item pages

Browse the [BOM item index](generated/parts/README.md) for a separate Markdown page for every catalog part, including optional and deferred items. Link directly to `bom/generated/parts/<part-id>.md` from other documents using a relative path. Stable part IDs keep these links usable when display names change.

Each page shows canonical requirements and notes, assembly usage quantities and inclusion status, links to the owning assembly documentation and BOM reports, and fabrication sources where recorded. Assembly `documentation` links are repository-relative paths in `assemblies/assemblies.json`. Quantities shown on item pages are per assembly definition; scenario reports apply build multipliers and inclusion policy.

Item pages and their index are generated: change canonical inputs and run `pnpm bom:generate`. `pnpm bom:check` detects missing, stale, and orphaned item pages. Both commands handle the complete item catalog even when a single scenario is requested.

## Physical ownership

The V1 build has five canonical physical root owners: the corner-support set, camera pod, dock, control cabinet, and site installation. The four-winch set is a child of the corner-support set and owns the four positioning lines; its powered variant additionally owns the hybrid-line conductors and slip ring. There is no separate positioning-line BOM owner. See [ADR-0010](../docs/decisions/0010-corner-support-and-winch-line-ownership.md). Site installation owns installed power and signal routes plus the deferred weather-sensing endpoint rather than promoting cabling or weather into type-based top-level subsystems. A complex root may gain physical child assemblies through `parentAssemblyId`; parent links must stay within the physical hierarchy and cannot self-reference or form cycles.

Builds explicitly include parent and child definitions once each. `parentAssemblyId` describes ownership; it does not recursively expand child quantities. Goods allocations remain direct-owner amounts, so support and winch costs are separate and are summed only once.

`shared-procurement-stock` is an explicitly typed, non-physical purchasing exception. It represents assortments whose exact installed size-level allocation is not yet defensible. Reports keep this stock separate and never describe it as subsystem ownership.

OpenSCAD-backed parts link to canonical entries under `hardware/assemblies`. Fabrication status can advance through `planned`, `concept-unvalidated`, `prototype`, `validated`, `released`, and `deprecated`. Planned parts have no claimed manufacturing source; every later status requires at least one linked source. Reference-only geometry studies are not claimed as fabrication sources.

## Offer qualification

Offer qualification is explicit:

- `approved`: engineering compatibility and procurement assumptions have supporting evidence.
- `baseline-selected`: the repository's current pinned selection, not yet approved.
- `candidate`: an alternative awaiting review.
- `unresolved`: a placeholder or materially incomplete offer.

A supplier link, order, or receipt alone is not engineering approval. Add alternate suppliers as new offers so price, packaging, and location comparisons remain reviewable in Git.

## Pricing and shipping

Quantities and money are decimal strings. The calculator uses BigInt-backed exact decimal arithmetic and never totals money with binary floating point.

An offer purchase unit can contain one part, a spool or box quantity, or several component types. This models a kit without assigning the purchasing bundle to the wrong physical assembly. Package rounding exposes purchased quantity and surplus, including:

- 180 m Dyneema from 50 m spools: 200 m purchased, 20 m surplus.
- 85 m Cat5e from a 100 m reel: 100 m purchased, 15 m surplus.
- 16 washers from a 100-piece box: 84 surplus.
- two servos from a three-pack: one surplus.
- five required microswitches from a ten-pack: five surplus.

Shipping belongs to a checkout group and is charged once. A supplier can own multiple checkout groups when seller, basket, or warehouse boundaries create separate charges; each offer selects exactly one group. Null shipping means unknown, never free. Different currencies are converted only through explicit rates committed in the quote snapshot.

A checkout quote can set `basis: "selected-offer"` to apply its fixed amount once per distinct selected offer in the group, independent of required quantity or purchase-unit count. Omitted basis defaults to `checkout-group`. Unselected offers incur no charge.

The [2026-09-08 Croatian quote](quotes/hr-zagreb-2026-09-08.json) applies the owner's EUR 3 delivery/customs allowance to each selected AliExpress offer for orders below EUR 150. This assumes one BOM offer per declared item and does not model split shipments or customs grouping. [Croatian Customs guidance](https://carina.gov.hr/print.aspx?id=2718&url=print) describes the duty per declared item. Other prices retain their earlier observation dates; this snapshot does not re-verify them. The earlier quote remains preserved.

The [BAUHAUS shaft revision of the 2026-09-08 quote](quotes/hr-zagreb-2026-09-08-bauhaus-shaft.json) preserves those observations and adds the owner-selected EUR 6.95, VAT-inclusive 2000 mm steel rod. The later segmented-drum layout allocates three 340 mm passive shafts and one 660 mm powered shaft from the same rod, superseding four approximately 400 mm blanks. Local availability, cutting/finishing cost and BAUHAUS shipping remain unknown; the earlier snapshot is preserved.

`capturedAt` records when a quote snapshot was assembled. It does not claim that every price, availability state, or shipping charge was observed at that instant. Individual rows use `observedAt: null` until a defensible observation time is known, and the calculator reports the missing evidence as a completeness warning.

The current [2026-10-08 purchase quote](quotes/hr-zagreb-2026-10-08-purchases.json) preserves those earlier observations and records the owner's four Barton BA01090 pulleys at EUR 14.20 each, EUR 56.80 total, collected in store with zero delivery charge. The scenario now selects `wasi-barton-30mm` instead of the unresolved combined supplier offer. [WASI purchase and shipping evidence](sourcing/wasi-pulley-2026-10-08.md) keeps the separate WASI delivery tariff for future orders; it is not charged to this purchase.

The same quote records the owner's four Dive Store 50 m spools at EUR 18.38 each, EUR 73.52 goods, plus EUR 6.91 actual delivery to Zagreb, EUR 80.43 total. The goods price matches the earlier EUR 0.3676/m observation; delivery replaces the earlier EUR 6.25. [Dive Store purchase evidence](sourcing/dive-store-line-2026-10-08.md) separates the confirmed total from supplier stock and the original purchase date, which remain unknown. VAT breakdowns were not supplied for either purchase. The earlier quotes remain preserved.

The [2026-10-08 coupling quote](quotes/hr-zagreb-2026-10-08-coupling.json) is now selected and records EUR 3.09 per piece and free Croatian delivery for the coupling. The [dated sourcing note](sourcing/coupling-2026-10-08.md) records the owner-confirmed EUR 16.12 actual delivered total for four couplings, with no additional VAT or customs added; the EUR 3.09 quoted unit price remains separate. The shared [customs policy](catalog/customs.json) applies EUR 3 per item type per order from 2026-07-01, with no end date set, for order goods strictly below EUR 150. The estimate is EUR 12.36 goods plus EUR 3 conditional customs, EUR 15.36; the actual delivered purchase total is EUR 16.12. The owner confirmed EUR 3.76 actual import charges: EUR 12.36 goods + EUR 0 delivery + EUR 3.76 import charges = EUR 16.12. Actual delivered totals are displayed separately and are not summed with estimated customs. Customs is separate from delivery in the report. Basket goods must be known and below the threshold; unknown or larger baskets leave actual duty unresolved. One selected offer approximates one declared item type; no split orders are assumed. Free delivery is confirmed for the coupling only. Earlier snapshots preserve their combined allowance.

In-house fabrication offers retain an unknown full quote while a separate material estimate accounts for the plastic consumed. The current [PETG Matte and bulk costing evidence](sourcing/petg-matte-bulk-2026-10-08.md) records Bambu Lab's 10+ mixed eligible 1 kg **filament-with-spool** rates, densities, White/Black variants and component-specific print choices. Eligible PLA Basic, PETG Basic and PETG Matte use bulk prices; ASA remains at its evidenced single-spool price because it is absent from the eligible bulk selection. Refill, coupon and membership prices are excluded. The [earlier single-spool record](sourcing/print-materials-2026-10-08.md) remains historical.

The calculator extends each chosen recipe by the required BOM quantity, preserves each component’s material and colour, then calculates **solid volume in cm³ × density in g/cm³ × roll price / roll grams** using exact decimal arithmetic. It applies each weight-based material cost once, including the separately owned funnel and nest within the shared dock offer. A quoted fabrication price supersedes its material allowance. Printed parts without procurement offers, such as the full cover, still receive an estimate. Optional/deferred prints remain outside the base subtotal.

The current weights are estimates of fully dense CAD plastic, not sliced or measured weights. Infill is not modeled by multiplying the entire mesh by a nominal infill percentage, which would incorrectly scale walls and skins. Supports, brims, purge, failed prints, filament shipping, Croatian checkout VAT adjustments, energy, machine time and labour remain unresolved. Changing print settings requires new slicer evidence; a material costing choice does not qualify it for physical use. Planned parts without geometry and machined metal parts retain unknown costs.

Reports expose `estimatedMaterialSubtotal` and `estimatedPartialSubtotal` alongside quoted goods and shipping. The website identifies estimated material amounts in each item row and assembly sum, and shows selected material/colour weights and PLA/PETG Basic/PETG Matte/ASA comparisons on included printed-item pages. `completeLandedTotal` remains unavailable. `not-applicable` in-house shipping describes the absence of a fabricated-part shipment; it does not make raw filament delivery or fabrication free.

Geometry evidence pins each STL checksum, model revision and the CAD source hashes. `bom:generate` and `bom:check` reject changed geometry until volumes are recaptured. To reproduce a release capture, download its `cad-release.json`, `SHA256SUMS.txt` and recipe STLs into an external directory and run:

```bash
python3 packages/arbi-bom/scripts/capture-print-volumes.py /path/to/cad-release-assets
pnpm bom:generate
pnpm bom:check
```

The capture script verifies source and release/STL checksums, closed consistently oriented mesh edges and positive signed volume before updating canonical evidence. It commits no generated meshes. The recipe lists select installed variants explicitly rather than totaling every linked fabrication source.

The capture tool and its independent mesh-volume tests use Python 3's standard library. Package tests include ASCII/binary volume-unit and invalid-mesh controls alongside the TypeScript costing regressions.

For changed CAD awaiting a release, omit the directory argument to export the current recipes with the registry-pinned OpenSCAD version. This uses temporary meshes, checks source hashes before/after export and records local evidence with `releaseTag: null`; `sourceCommit` is the base commit, while source hashes identify the exact geometry. The website compiler also rejects stale geometry evidence.

## Reports

System pages expand costed print kits into model IDs, copy quantities, material
assignments and individual consumption estimates. Component amounts retain four
decimal places; material-group and kit totals retain their existing cent rounding.
CAD file counts also include assembly references, alternatives and test pieces,
so they are not physical quantities or expected BOM row counts.

The compact pod now owns explicit fastener and internal-wiring sets; the cabinet
owns mounting/termination and protection/stop-interface sets for the previously
unmapped layout reserves. Their required quantities are one set per assembly.
Exact kit requirements are in the catalog; unresolved products and quotes remain
visible as missing prices. Reconcile OEM accessories and shared procurement
stock before ordering. Optional head and stand print sets carry ASA consumption
estimates as costing assumptions only; machined metal and full fabrication costs
remain unknown. This does not resolve the report's completeness warnings.

### Delivery tracking

[Order and receipt log](receipts.md) records orders, incoming items, and actual deliveries confirmed by the owner, using the stable offer IDs from `catalog/offers.json`. Keep actual ordered/received quantities and confirmation dates separate from calculated purchase quantities; leave unspecified quantities unknown. Items absent from the log have no recorded order or receipt status. These records do not change offer qualification or establish inspection, testing, or installation status.

The receipt log is maintained manually and is not consumed by the BOM calculator or generated reports.

`generated/arbi-v1-hr-zagreb.json` is the deterministic machine-readable result. `generated/arbi-v1-hr-zagreb.md` is the GitHub-readable report.

The current report is intentionally incomplete. It exposes a known partial subtotal but leaves the complete landed total unavailable while package rules, prices, tax treatment, shipping, availability, and qualification remain unresolved. The partial subtotal must not be presented as the project cost.

Bundle goods for countable components (`each`) are allocated in proportion to the quantity of each part in the purchased bundle, including surplus. For example, a kit with four motors, four drivers, four cables and two power supplies assigns 4/14 of its goods cost to each four-piece line and 2/14 to the power supplies. These are accounting shares, not individual supplier prices. Exact cent allocation uses largest remainders with part ID as the tie-breaker, so shares sum to the quoted bundle amount. Each part's share is then allocated across its owners by required quantity. Reports and the website display those shares and include them in assembly goods totals without counting the bundle again.

Unknown bundle prices remain unknown. Costs for unselected bundle contents and bundles whose contents are not all countable components remain in the shared bundle bucket. Checkout shipping stays separate from physical-assembly goods.

The file calculator supports deterministic pinned selection and honest incomplete reporting. Cheapest-compliant selection, quote-staleness optimization, lead-time planning, and interactive destination comparison are future website capabilities, not current CLI claims.

## Commands

Run from the repository root:

```bash
pnpm --filter @arbi/bom build
pnpm --filter @arbi/bom lint
pnpm --filter @arbi/bom typecheck
pnpm --filter @arbi/bom test
pnpm --filter @arbi/bom generate
pnpm --filter @arbi/bom check
```

`generate` validates every canonical input against the committed JSON Schemas, applies cross-file engineering validation, and writes tracked `<scenario-id>.json` and `<scenario-id>.md` reports for every scenario. `check` performs the same validation, calculates every expected report without modifying files, and fails when a tracked artifact is missing or stale. Pass a scenario ID after either command to operate on one scenario explicitly.

## Contribution workflow

1. Change canonical inputs, never generated reports.
2. Preserve stable IDs; change display names without renaming IDs.
3. Add alternative suppliers as new offers rather than overwriting existing observations.
4. Record package contents, minimum, increment, observed price, currency, destination, tax treatment, checkout group, and observation date. Use null for unknown.
5. Reserve `approved` for an evidence-backed engineering qualification.
6. Add complex physical subassemblies under one of the five roots with `parentAssemblyId`; keep `shared-procurement-stock` outside the physical hierarchy.
7. Run package tests and `generate`, then commit both canonical inputs and generated changes.
8. Treat calculation, OpenSCAD compilation, procurement, installation, and physical safety validation as separate evidence.

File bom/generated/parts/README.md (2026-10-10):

# BOM item pages

> Generated from canonical BOM inputs by `pnpm bom:generate`. Do not edit this page by hand.

[Back to the BOM](../../README.md)

One stable page per catalog part, including optional and deferred items. Usage quantities belong to the named assembly definition; scenario reports apply build quantities and inclusion policy.

| Item | Part ID |
| --- | --- |
| [AS5600 magnetic angle sensor + magnet](as5600-angle-sensor.md) | as5600-angle-sensor |
| [608-2RS sealed bearing](bearing-608-2rs.md) | bearing-608-2rs |
| [1000 µF 5 V rail bulk capacitor](bulk-capacitor-1000uf.md) | bulk-capacitor-1000uf |
| [Cabinet mounting and internal termination set](cabinet-installation-kit.md) | cabinet-installation-kit |
| [Cabinet protection and hardwired stop interface set](cabinet-protection-kit.md) | cabinet-protection-kit |
| [IP68 cable gland assortment](cable-gland-assortment.md) | cable-gland-assortment |
| [Pan/tilt camera gimbal](camera-gimbal.md) | camera-gimbal |
| [Camera pod spider/chassis](camera-pod-chassis.md) | camera-pod-chassis |
| [Compact camera pod bought fastener set](camera-pod-fastener-kit.md) | camera-pod-fastener-kit |
| [Camera pod internal wiring and retention set](camera-pod-wiring-kit.md) | camera-pod-wiring-kit |
| [Capsule slip ring, ≥6 channels × 2 A](capsule-slip-ring-6x2a.md) | capsule-slip-ring-6x2a |
| [CL57Y-V20 closed-loop motor driver](cl57y-v20-driver.md) | cl57y-v20-driver |
| [Central outdoor electrical cabinet](control-panel-enclosure.md) | control-panel-enclosure |
| [48 V → 5 V controller buck converter](controller-buck-converter-48v-5v.md) | controller-buck-converter-48v-5v |
| [Reviewed bought guy-to-post attachment set](corner-guy-post-connection.md) | corner-guy-post-connection |
| [Proposed 200 mm top-pulley steel angle](corner-head-angle-200.md) | corner-head-angle-200 |
| [Corner head reusable centre marking template](corner-head-marking-template.md) | corner-head-marking-template |
| [Printed corner-head bought fastener and retention set](corner-head-printed-hardware.md) | corner-head-printed-hardware |
| [Printed corner-head carrier, pads and covers kit](corner-head-printed-kit.md) | corner-head-printed-kit |
| [Printed-head shared timber centre marking template](corner-head-printed-marking-template.md) | corner-head-printed-marking-template |
| [Corner head replaceable shield retention straps](corner-head-retention-straps.md) | corner-head-retention-straps |
| [Corner head round-timber metal saddle pair](corner-head-round-saddles.md) | corner-head-round-saddles |
| [Proposed round-head M12 through-bolt pair](corner-head-through-bolts.md) | corner-head-through-bolts |
| [Corner head removable weather shield kit](corner-head-weather-kit.md) | corner-head-weather-kit |
| [Ground-contact treated timber corner post](corner-post-treated-timber.md) | corner-post-treated-timber |
| [Optional WT-806 indoor corner-station adapter kit](corner-stand-adapter-kit.md) | corner-stand-adapter-kit |
| [DIN-rail GND distribution block](din-rail-ground-distribution-block.md) | din-rail-ground-distribution-block |
| [DOCK-IF-01 bought fastener set](dock-bench-hardware.md) | dock-bench-hardware |
| [High-dock alignment funnel](dock-funnel.md) | dock-funnel |
| [DOCK-IF-01 fork, structural pod bridge and stud print set](dock-latch-hardware.md) | dock-latch-hardware |
| [High-dock locating nest](dock-nest.md) | dock-nest |
| [Split dock support arm and rear pads](dock-support-arm.md) | dock-support-arm |
| [Dock weather roof / hood](dock-weather-hood.md) | dock-weather-hood |
| [1.5 mm Dyneema positioning line, 50 m](dyneema-positioning-line.md) | dyneema-positioning-line |
| [Waterproof emergency-stop switch](emergency-stop-switch.md) | emergency-stop-switch |
| [Stainless extension spring assortment](extension-spring-assortment.md) | extension-spring-assortment |
| [8 mm → 8 mm flexible jaw coupling](flexible-jaw-coupling-8mm.md) | flexible-jaw-coupling-8mm |
| [Guy ground anchor](guy-ground-anchor.md) | guy-ground-anchor |
| [M12 guy turnbuckle](guy-turnbuckle-m12.md) | guy-turnbuckle-m12 |
| [3 mm stainless/galvanized guy wire](guy-wire-3mm.md) | guy-wire-3mm |
| [Heat-set threaded insert assortment](heat-set-insert-assortment.md) | heat-set-insert-assortment |
| [Matched closed-loop motor cable](matched-motor-cable.md) | matched-motor-cable |
| [Micro pan/tilt servo](micro-pan-tilt-servo.md) | micro-pan-tilt-servo |
| [32 GB microSD card](microsd-card-32gb.md) | microsd-card-32gb |
| [48 V motor power branch cable](motor-power-branch-cable.md) | motor-power-branch-cable |
| [3.0 Nm NEMA 23 closed-loop motor](nema23-closed-loop-motor.md) | nema23-closed-loop-motor |
| [Outdoor Cat5e signal cable](outdoor-cat5e-signal-cable.md) | outdoor-cat5e-signal-cable |
| [52Pi EP-0145 Screw Terminal Expansion Board](pico-terminal-expansion-board.md) | pico-terminal-expansion-board |
| [48 V → 5 V pod buck converter](pod-buck-converter-48v-5v.md) | pod-buck-converter-48v-5v |
| [AWG26 flexible silicone wire — black](pod-power-wire-black-awg26.md) | pod-power-wire-black-awg26 |
| [AWG26 flexible silicone wire — red](pod-power-wire-red-awg26.md) | pod-power-wire-red-awg26 |
| [Round-pole split-clamp pulley mount concept pair](pole-pulley-mount-concept.md) | pole-pulley-mount-concept |
| [IP65/IP67 ABS post electronics box](post-electronics-enclosure.md) | post-electronics-enclosure |
| [48 V / 350 W power supply](power-supply-48v-350w.md) | power-supply-48v-350w |
| [Rear backing plate for top-pulley bracket — stacked BAUHAUS plates](pulley-bracket-backing-plate.md) | pulley-bracket-backing-plate |
| [M12 galvanized locking nut for pulley bracket](pulley-bracket-locknut-m12.md) | pulley-bracket-locknut-m12 |
| [M8 A4 shackle for pulley-to-bracket connection](pulley-bracket-shackle-m8.md) | pulley-bracket-shackle-m8 |
| [M12 × 160 galvanized 8.8 through-bolt for pulley bracket](pulley-bracket-through-bolt-m12x160.md) | pulley-bracket-through-bolt-m12x160 |
| [M12 DIN 9021 large washer for pulley bracket](pulley-bracket-washer-m12.md) | pulley-bracket-washer-m12 |
| [Raspberry Pi 3A+](raspberry-pi-3a-plus.md) | raspberry-pi-3a-plus |
| [Raspberry Pi Camera Module 3 Standard](raspberry-pi-camera-module-3.md) | raspberry-pi-camera-module-3 |
| [Raspberry Pi Pico 2 W with headers](raspberry-pi-pico-2-w.md) | raspberry-pi-pico-2-w |
| [Winch home/reference and docked position roller microswitch](roller-lever-microswitch.md) | roller-lever-microswitch |
| [8 mm clamp shaft collar](shaft-collar-8mm.md) | shaft-collar-8mm |
| [Stainless metric fastener assortment](stainless-fastener-assortment.md) | stainless-fastener-assortment |
| [Top positioning-line pulley](top-positioning-line-pulley.md) | top-positioning-line-pulley |
| [Top-pulley offset steel mounting bracket — BAUHAUS Stabilit solid angle](top-pulley-bracket.md) | top-pulley-bracket |
| [Top-pulley Dyneema keeper / weather cover](top-pulley-keeper.md) | top-pulley-keeper |
| [Underground cable sleeve](underground-cable-sleeve.md) | underground-cable-sleeve |
| [Optional passive winch desk-foot kit](winch-desk-feet.md) | winch-desk-feet |
| [Single-layer grooved winch drum](winch-drum.md) | winch-drum |
| [Joining and clamp hardware for four segmented drums](winch-drum-joining-hardware.md) | winch-drum-joining-hardware |
| [8 mm steel drum shaft (variant cut allowance)](winch-drum-shaft-8mm.md) | winch-drum-shaft-8mm |
| [Mechanical drum lock / fail-safe brake](winch-fail-safe-brake.md) | winch-fail-safe-brake |
| [Modular full-winch protective shell kit](winch-full-cover.md) | winch-full-cover |
| [Four-winch full-cover fastening and loom allowance](winch-full-cover-hardware.md) | winch-full-cover-hardware |
| [Winch bearing/motor mount and guard](winch-mount-and-guard.md) | winch-mount-and-guard |
| [Rigid bases, bearing spacers and fasteners for four winch mounts](winch-mount-hardware.md) | winch-mount-hardware |
| [Round timber-pole machined metal saddle kit](winch-round-pole-adapter.md) | winch-round-pole-adapter |
| [Round-pole nut covers and cable guide kit](winch-round-pole-covers.md) | winch-round-pole-covers |
| [One-winch round-pole fastening allowance](winch-round-pole-hardware.md) | winch-round-pole-hardware |
| [3.3 V RS485 transceiver module for wind sensor](wind-sensor-rs485-transceiver.md) | wind-sensor-rs485-transceiver |
| [RS485/Modbus wind-speed sensor](wind-speed-sensor.md) | wind-speed-sensor |
| [3 mm wire-rope clamp](wire-rope-clamp-3mm.md) | wire-rope-clamp-3mm |
| [3 mm wire-rope thimble](wire-rope-thimble-3mm.md) | wire-rope-thimble-3mm |
| [Zinc-rich spray for drilled pulley-bracket edges](zinc-spray.md) | zinc-spray |

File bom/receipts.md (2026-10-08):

# BOM order and receipt log

Owner-confirmed orders and deliveries for the ARBI V1 build, linked by offer ID to the [offer catalog](catalog/offers.json). Actual ordered and received quantities are kept separate from the calculator's planned purchase quantities.

## Incoming orders confirmed on 2026-09-08

Evidence: Aleks reported that the following AliExpress items were ordered and are incoming, then confirmed the quantities and pack sizes below on 2026-09-08. Order dates and arrival estimates were not supplied.

| Supplier | Offer ID / BOM mapping | Item reported | Ordered quantity | Status |
| --- | --- | --- | --- | --- |
| AliExpress | `aliexpress-micro-pan-tilt-servo` | 3 g micro servos | 6 servos (2 packs × 3 pcs) | Ordered / incoming |
| AliExpress | `aliexpress-flexible-jaw-coupling-8mm` | Couplings | 4 couplers | Ordered / incoming |
| AliExpress | `aliexpress-controller-buck-converter-48v-5v`, `aliexpress-pod-buck-converter-48v-5v` (allocation unconfirmed) | Step-down converters | 4 converters total | Ordered / incoming |
| AliExpress | `aliexpress-roller-lever-microswitch` | Microswitches | 10 switches (1 pack × 10 pcs) | Ordered / incoming |
| AliExpress | `aliexpress-shaft-collar-8mm` | Split shaft collars | 8 collars (2 packs × 4 pcs) | Ordered / incoming |

Mappings identify the corresponding BOM items; exact ordered variants have not been checked. The step-down order is recorded as a single category pending confirmation of allocation to the controller and pod. These entries do not establish receipt or inspection, and planned pack sizes are not treated as confirmed order quantities.

## Receipts confirmed on 2026-09-08

Evidence: Aleks reported receiving the motor kit, four 50 m line spools, camera module, and Raspberry Pi microcontroller, then explicitly confirmed that all these and the other two identified TME items should be marked received. The date is the confirmation date; exact delivery dates were not supplied.

| Supplier | Offer ID / BOM mapping | Item | Received quantity | Status |
| --- | --- | --- | --- | --- |
| StepperOnline | `stepperonline-4-axis-v2-kit` | Four-axis motor kit, 4-CLYS30-V20 | 1 kit | Received |
| Dive Store | `dive-store-dyneema-positioning-line` | Dyneema positioning line | 4 × 50 m spools (200 m total) | Received |
| TME | `tme-raspberry-pi-camera-module-3` | Raspberry Pi Camera Module 3 | 1 | Received |
| TME | `tme-raspberry-pi-pico-2-w` | Raspberry Pi Pico 2 W with headers | 1 | Received |
| TME | `tme-microsd-card-32gb` | SanDisk 32 GB microSD card | 1 | Received |
| TME | `tme-pico-terminal-expansion-board` | Pico screw-terminal expansion board | 1 | Received |
| WASI Zagreb (BOM listing) | `baseline-combined-top-pulley-offer` | Top positioning-line rollers / pulleys | 4 | Received |

Aleks also confirmed receipt of four top rollers on 2026-09-08 and clarified that the supplier is the one in the BOM. The selected `baseline-combined-top-pulley-offer` links to WASI Zagreb. Its catalog supplier ID remains `baseline-top-pulley-combined` (Combined top-pulley source); this receipt uses that selected offer and identifies the seller from its listing. Exact delivered model has not been inspected.

Aleks explicitly confirmed on 2026-09-08 that the received motor kit and positioning lines are from the selected BOM offers: `stepperonline-4-axis-v2-kit` (StepperOnline) and `dive-store-dyneema-positioning-line` (Dive Store). The receipt entries above reflect those confirmed sources.

The catalog lists four motors, four CL57Y-V20 drivers, four matched motor cables, and two 48 V / 350 W power supplies inside the motor kit. Receipt is recorded at kit level; no separate contents inspection was reported.

Exact delivered camera and terminal-board variants have not been inspected against the BOM requirements. Receipt does not resolve existing catalog qualification or model discrepancies, or establish functional testing or installation.

## WASI purchase details confirmed on 2026-10-08

Evidence: Aleks identified the four previously received WASI pulleys as **BA01090**
and confirmed **EUR 56.80 total**, collected in store with **no delivery charge**.
This clarifies the 2026-09-08 receipt above; it is the same four units, not an
additional order. Exact order and collection dates were not supplied.

| Supplier | Current offer ID / BOM mapping | Item | Quantity | Goods total | Delivery | Status |
| --- | --- | --- | ---: | ---: | ---: | --- |
| WASI Zagreb | `wasi-barton-30mm` / `top-positioning-line-pulley` | Barton BA01090 30 mm STANDARD pulley | 4 | EUR 56.80 (EUR 14.20 each) | EUR 0 — store pickup | Received; owner-confirmed SKU |

The current scenario selects the existing WASI offer `wasi-barton-30mm`; the older
combined offer mapping above is retained as receipt history. See
[purchase and shipping evidence](sourcing/wasi-pulley-2026-10-08.md). No invoice VAT
breakdown or inspection, testing or installation evidence was supplied.

## Dive Store purchase details confirmed on 2026-10-08

Evidence: Aleks confirmed that the four previously received 50 m spools cost
**EUR 80.43 including EUR 6.91 delivery** to Zagreb. This clarifies the 2026-09-08
receipt above; it is the same four spools, not an additional order. Exact order
and delivery dates were not supplied.

| Supplier | Offer ID / BOM mapping | Item | Quantity | Goods total | Delivery | Total |
| --- | --- | --- | --- | ---: | ---: | ---: |
| Dive Store | `dive-store-dyneema-positioning-line` / `dyneema-positioning-line` | Dyneema positioning line | 4 × 50 m spools (200 m total) | EUR 73.52 (EUR 18.38 per spool) | EUR 6.91 — Zagreb | EUR 80.43 |

See [purchase evidence](sourcing/dive-store-line-2026-10-08.md). No VAT breakdown,
current stock observation or inspection, testing or installation evidence was
supplied.

## Coupling total confirmed on 2026-10-08

Aleks confirmed **EUR 16.12 actual delivered total for four couplings** linked to `aliexpress-flexible-jaw-coupling-8mm`, including all charges. The quoted price is EUR 3.09 per piece with free delivery. The EUR 15.36 goods-plus-customs estimate is not the actual total; actual import charges were **EUR 3.76**, giving EUR 12.36 goods + EUR 0 delivery + EUR 3.76 import charges = EUR 16.12. Do not add VAT or customs again to EUR 16.12. This clarifies the existing four-coupling order, not an additional order. Receipt status and exact order/delivery dates were not supplied. See [coupling price evidence](sourcing/coupling-2026-10-08.md).

Append future orders and deliveries with their confirmation date, evidence, stable offer ID, and actual quantity when known. When incoming items arrive, record receipt separately so the order history remains traceable. Do not infer receipt for unlisted items. This manual log is not included in generated cost reports.

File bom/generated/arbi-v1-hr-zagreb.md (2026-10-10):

# BOM — ARBI V1 — Zagreb repository baseline

> **Status: INCOMPLETE. This is not a trustworthy complete landed total.**
> Unknown package rules, prices, tax treatment, shipping, availability, and unqualified baseline selections remain visible below. Null values are never treated as zero.

[BOM overview](../README.md) · [All item pages](parts/README.md)

## Calculation identity

- Scenario: arbi-v1-hr-zagreb
- Build: arbi-v1
- Destination: hr-zagreb
- Quote snapshot: hr-zagreb-2026-10-08-coupling
- Input digest: sha256:f3057ac4a7070ce24e5387f8a8891263c3853d90ef5313e5ea0cd51f6099815a
- Complete landed total: **unavailable**
- Known quoted goods subtotal: **EUR 943.84**
- Known checkout-group shipping subtotal: **EUR 43.38**
- Known partial subtotal: **EUR 987.22**
- Estimated print materials: **EUR 254.45**
- Estimated partial subtotal (known amounts + print materials): **EUR 1241.67**

The known partial subtotal is evidence about recorded values only. It excludes every unresolved amount and must not be presented as the project cost.

## Physical assembly goods

| Physical assembly | Known allocated goods |
| --- | ---: |
| camera-pod | EUR 115.07 |
| control-cabinet | EUR 66.16 |
| corner-support-set | EUR 185.97 |
| dock | EUR 1.60 |
| site-installation | EUR 141.00 |
| winch-set | EUR 390.85 |
| Shared multi-part purchase bundles | EUR 0.00 |
| Shared customs | EUR 0.00 |
| Shared checkout-group shipping | EUR 43.38 |

Multi-part bundles of countable components are allocated by purchased part count, including surplus, with cents distributed deterministically. These shares are accounting allocations, not individual supplier prices. Unselected contents or bundles without comparable part counts remain in the shared bundle bucket; shipping remains separate.

## Estimated print material costs

Solid CAD volume × each component's material density × observed roll price / roll grams. Eligible PLA/PETG rates assume 10+ mixed eligible filament-with-spool rolls in one Bambu EU bulk order; ASA retains its evidenced single-spool price. These consumption estimates exclude supports, purge, failures, energy, machine time, labour, filament shipping and destination VAT adjustments. They do not make the landed total complete.

| Part | Required | Material | Estimated weight | Estimated material cost |
| --- | ---: | --- | ---: | ---: |
| [camera-gimbal](parts/camera-gimbal.md) | 1 | PETG Matte + PETG Basic | 54.004 g | EUR 0.61 |
| [camera-pod-chassis](parts/camera-pod-chassis.md) | 1 | PETG Matte + PETG Basic | 207.265 g | EUR 2.36 |
| [dock-funnel](parts/dock-funnel.md) | 1 | PETG Basic | 149.073 g | EUR 1.70 |
| [dock-latch-hardware](parts/dock-latch-hardware.md) | 1 | PETG Basic | 126.828 g | EUR 1.44 |
| [dock-nest](parts/dock-nest.md) | 1 | PETG Basic | 216.782 g | EUR 2.47 |
| [dock-support-arm](parts/dock-support-arm.md) | 1 | PETG Basic | 1602.762 g | EUR 18.26 |
| [dock-weather-hood](parts/dock-weather-hood.md) | 1 | PETG Basic | 299.523 g | EUR 3.41 |
| [top-pulley-keeper](parts/top-pulley-keeper.md) | 4 | PETG Basic | 110.733 g | EUR 1.26 |
| [winch-drum](parts/winch-drum.md) | 4 | PETG Basic | 4980.607 g | EUR 56.73 |
| [winch-full-cover](parts/winch-full-cover.md) | 4 | ASA + PETG Matte | 12527.69 g | EUR 147.84 |
| [winch-mount-and-guard](parts/winch-mount-and-guard.md) | 4 | PETG Matte + PETG Basic | 1613.452 g | EUR 18.37 |

## Non-physical procurement bucket

| Purchasing bucket | Known directly attributable goods |
| --- | ---: |
| shared-procurement-stock | EUR 43.19 |

This bucket is not a subsystem or physical owner. It holds assortment purchases until consumption can be allocated to an installed assembly.

## Checkout groups

| Checkout group | Supplier | Shipping evidence | Charged |
| --- | --- | --- | ---: |
| aliexpress-hr | aliexpress | unknown | unknown |
| bauhaus-hr | bauhaus | unknown | unknown |
| cotra-zagreb-hr | cotra-zagreb | unknown | unknown |
| dive-store-hr | dive-store | known | EUR 6.91 |
| in-house-fabrication-hr | in-house-fabrication | not-applicable | not applicable |
| kabel24-hr | kabel24 | unknown | unknown |
| njuskalo-hr | njuskalo | unknown | unknown |
| pimoroni-hr | pimoroni | unknown | unknown |
| ronis-hr | ronis | unknown | unknown |
| stepperonline-hr | stepperonline | known | EUR 34.01 |
| tme-hr | tme | known | EUR 2.46 |
| wasi-hr | wasi | not-applicable | not applicable |

Shipping is evaluated once per checkout group. The recorded TME EUR 2.46 charge is represented once.

## Customs

Known customs subtotal: EUR 0.00. Conditional or unknown duty is excluded from the known subtotal.

aliexpress-hr: EUR 3.00 per item type (not per piece), order goods strictly below EUR 150.00; effective 2026-07-01 until no end date set (exclusive end). 15 item types; calculated charge: unknown. Owner costing policy: EUR 3 per declared item type, not per piece, for orders strictly below EUR 150. One selected offer approximates one declared item type; actual tariff/description/origin grouping and split shipments require checkout evidence. Customs guidance includes EUR 150; this policy uses the owner-requested strict limit. VAT is separate. No end date currently recorded.

## Selected purchase units

| Offer | Qualification | Purchase units | Coverage and surplus | Known goods | Allocation |
| --- | --- | ---: | --- | ---: | --- |
| aliexpress-bearing-608-2rs | baseline-selected | 1 | [bearing-608-2rs](parts/bearing-608-2rs.md): 10 each required, 10 each purchased; 0 surplus; goods EUR 3.97 | EUR 3.97 | single-part |
| aliexpress-bulk-capacitor-1000uf | baseline-selected | 1 | [bulk-capacitor-1000uf](parts/bulk-capacitor-1000uf.md): 2 each required, 20 each purchased; 18 surplus; goods EUR 3.29 | EUR 3.29 | single-part |
| aliexpress-cable-gland-assortment | baseline-selected | 1 | [cable-gland-assortment](parts/cable-gland-assortment.md): 1 each required, 1 each purchased; 0 surplus; goods EUR 11.19 | EUR 11.19 | single-part |
| aliexpress-capsule-slip-ring-6x2a | baseline-selected | 1 | [capsule-slip-ring-6x2a](parts/capsule-slip-ring-6x2a.md): 1 each required, 1 each purchased; 0 surplus; goods EUR 9.69 | EUR 9.69 | single-part |
| aliexpress-controller-buck-converter-48v-5v | baseline-selected | 1 | [controller-buck-converter-48v-5v](parts/controller-buck-converter-48v-5v.md): 1 each required, 1 each purchased; 0 surplus; goods EUR 5.55 | EUR 5.55 | single-part |
| aliexpress-emergency-stop-switch | baseline-selected | unknown | [emergency-stop-switch](parts/emergency-stop-switch.md): 1 each required, unknown purchase quantity; goods unknown | unknown | unallocated |
| aliexpress-flexible-jaw-coupling-8mm | baseline-selected | 4 | [flexible-jaw-coupling-8mm](parts/flexible-jaw-coupling-8mm.md): 4 each required, 4 each purchased; 0 surplus; goods EUR 12.36 | EUR 12.36 | single-part |
| aliexpress-heat-set-insert-assortment | baseline-selected | 1 | [heat-set-insert-assortment](parts/heat-set-insert-assortment.md): 1 each required, 1 each purchased; 0 surplus; goods EUR 16.00 | EUR 16.00 | single-part |
| aliexpress-micro-pan-tilt-servo | baseline-selected | 1 | [micro-pan-tilt-servo](parts/micro-pan-tilt-servo.md): 2 each required, 3 each purchased; 1 surplus; goods EUR 16.72 | EUR 16.72 | single-part |
| aliexpress-pod-buck-converter-48v-5v | baseline-selected | 1 | [pod-buck-converter-48v-5v](parts/pod-buck-converter-48v-5v.md): 1 each required, 1 each purchased; 0 surplus; goods EUR 5.55 | EUR 5.55 | single-part |
| aliexpress-pod-power-wire-black-awg26 | baseline-selected | 10 | [pod-power-wire-black-awg26](parts/pod-power-wire-black-awg26.md): 50 m required, 50 m purchased; 0 surplus; goods EUR 10.38 | EUR 10.38 | single-part |
| aliexpress-pod-power-wire-red-awg26 | baseline-selected | 10 | [pod-power-wire-red-awg26](parts/pod-power-wire-red-awg26.md): 50 m required, 50 m purchased; 0 surplus; goods EUR 10.38 | EUR 10.38 | single-part |
| aliexpress-roller-lever-microswitch | baseline-selected | 1 | [roller-lever-microswitch](parts/roller-lever-microswitch.md): 6 each required, 10 each purchased; 4 surplus; goods EUR 4.79 | EUR 4.79 | single-part |
| aliexpress-shaft-collar-8mm | baseline-selected | 4 | [shaft-collar-8mm](parts/shaft-collar-8mm.md): 8 each required, 8 each purchased; 0 surplus; goods EUR 40.40 | EUR 40.40 | single-part |
| aliexpress-stainless-fastener-assortment | baseline-selected | 1 | [stainless-fastener-assortment](parts/stainless-fastener-assortment.md): 1 each required, 1 each purchased; 0 surplus; goods EUR 16.00 | EUR 16.00 | single-part |
| bauhaus-din-rail-ground-distribution-block | baseline-selected | 1 | [din-rail-ground-distribution-block](parts/din-rail-ground-distribution-block.md): 1 each required, 1 each purchased; 0 surplus; goods EUR 5.95 | EUR 5.95 | single-part |
| bauhaus-guy-turnbuckle-m12 | baseline-selected | unknown | [guy-turnbuckle-m12](parts/guy-turnbuckle-m12.md): 4 each required, unknown purchase quantity; goods unknown | unknown | unallocated |
| bauhaus-guy-wire-3mm | baseline-selected | unknown | [guy-wire-3mm](parts/guy-wire-3mm.md): 16 m required, unknown purchase quantity; goods unknown | unknown | unallocated |
| bauhaus-motor-power-branch-cable | baseline-selected | 1 | [motor-power-branch-cable](parts/motor-power-branch-cable.md): 50 m required, 50 m purchased; 0 surplus; goods EUR 89.00 | EUR 89.00 | single-part |
| bauhaus-post-electronics-enclosure | baseline-selected | unknown | [post-electronics-enclosure](parts/post-electronics-enclosure.md): 4 each required, unknown purchase quantity; goods unknown | unknown | unallocated |
| bauhaus-pulley-bracket-backing-plate | baseline-selected | 8 | [pulley-bracket-backing-plate](parts/pulley-bracket-backing-plate.md): 8 each required, 8 each purchased; 0 surplus; goods EUR 28.40 | EUR 28.40 | single-part |
| bauhaus-pulley-bracket-locknut-m12 | baseline-selected | 1 | [pulley-bracket-locknut-m12](parts/pulley-bracket-locknut-m12.md): 8 each required, 50 each purchased; 42 surplus; goods EUR 9.00 | EUR 9.00 | single-part |
| bauhaus-pulley-bracket-shackle-m8 | baseline-selected | 4 | [pulley-bracket-shackle-m8](parts/pulley-bracket-shackle-m8.md): 4 each required, 4 each purchased; 0 surplus; goods EUR 14.28 | EUR 14.28 | single-part |
| bauhaus-pulley-bracket-through-bolt-m12x160 | baseline-selected | 1 | [pulley-bracket-through-bolt-m12x160](parts/pulley-bracket-through-bolt-m12x160.md): 8 each required, 40 each purchased; 32 surplus; goods EUR 33.20 | EUR 33.20 | single-part |
| bauhaus-pulley-bracket-washer-m12 | baseline-selected | 1 | [pulley-bracket-washer-m12](parts/pulley-bracket-washer-m12.md): 16 each required, 100 each purchased; 84 surplus; goods EUR 16.00 | EUR 16.00 | single-part |
| bauhaus-top-pulley-bracket | baseline-selected | 4 | [top-pulley-bracket](parts/top-pulley-bracket.md): 4 each required, 4 each purchased; 0 surplus; goods EUR 16.60 | EUR 16.60 | single-part |
| bauhaus-winch-drum-shaft-8mm | baseline-selected | 1 | [winch-drum-shaft-8mm](parts/winch-drum-shaft-8mm.md): 4 each required, 4 each purchased; 0 surplus; goods EUR 6.95 | EUR 6.95 | single-part |
| bauhaus-wire-rope-clamp-3mm | baseline-selected | unknown | [wire-rope-clamp-3mm](parts/wire-rope-clamp-3mm.md): 16 each required, unknown purchase quantity; goods unknown | unknown | unallocated |
| bauhaus-wire-rope-thimble-3mm | baseline-selected | unknown | [wire-rope-thimble-3mm](parts/wire-rope-thimble-3mm.md): 8 each required, unknown purchase quantity; goods unknown | unknown | unallocated |
| bauhaus-zinc-spray | baseline-selected | 1 | [zinc-spray](parts/zinc-spray.md): 1 each required, 1 each purchased; 0 surplus; goods EUR 11.69 | EUR 11.69 | single-part |
| cotra-zagreb-corner-post-treated-timber | baseline-selected | unknown | [corner-post-treated-timber](parts/corner-post-treated-timber.md): 4 each required, unknown purchase quantity; goods unknown | unknown | unallocated |
| dive-store-dyneema-positioning-line | baseline-selected | 4 | [dyneema-positioning-line](parts/dyneema-positioning-line.md): 180 m required, 200 m purchased; 20 surplus; goods EUR 73.52 | EUR 73.52 | single-part |
| in-house-fabrication-camera-gimbal | baseline-selected | 1 | [camera-gimbal](parts/camera-gimbal.md): 1 each required, 1 each purchased; 0 surplus; goods unknown | unknown | unallocated |
| in-house-fabrication-camera-pod-chassis | baseline-selected | 1 | [camera-pod-chassis](parts/camera-pod-chassis.md): 1 each required, 1 each purchased; 0 surplus; goods unknown | unknown | unallocated |
| in-house-fabrication-dock-capture-set | baseline-selected | 1 | [dock-funnel](parts/dock-funnel.md): 1 each required, 1 each purchased; 0 surplus; goods unknown; [dock-nest](parts/dock-nest.md): 1 each required, 1 each purchased; 0 surplus; goods unknown | unknown | unallocated |
| in-house-fabrication-dock-latch-hardware | baseline-selected | 1 | [dock-latch-hardware](parts/dock-latch-hardware.md): 1 each required, 1 each purchased; 0 surplus; goods unknown | unknown | unallocated |
| in-house-fabrication-dock-weather-hood | baseline-selected | 1 | [dock-weather-hood](parts/dock-weather-hood.md): 1 each required, 1 each purchased; 0 surplus; goods unknown | unknown | unallocated |
| in-house-fabrication-top-pulley-keeper | baseline-selected | 4 | [top-pulley-keeper](parts/top-pulley-keeper.md): 4 each required, 4 each purchased; 0 surplus; goods unknown | unknown | unallocated |
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

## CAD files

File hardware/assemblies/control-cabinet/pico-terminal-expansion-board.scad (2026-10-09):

// pico-terminal-expansion-board — r0.1.0, concept-unvalidated.
// Approximate visualization only; not a manufacturing source. Units: mm.
// Assumed 90 × 60 × 18 mm terminal-board envelope; EP-0145 mounting and terminal geometry unverified.
// Shape is not yet fully defined. Confirm the selected item against supplier drawings or measurements, then rework this model before using it for fit, clearance or fabrication.
include <../../lib/catalog-visualizations.scad>

module cabinet_pico_terminal_board() {
    arbi_catalog_visualization("terminal_board", [90, 60, 18]);
}
cabinet_pico_terminal_board();

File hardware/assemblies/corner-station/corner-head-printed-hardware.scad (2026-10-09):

// corner-head-printed-hardware — r0.1.0, concept-unvalidated.
// Approximate visualization only; not a manufacturing source. Units: mm.
// Representative catalog M12 × 190 and M8 × 100 bolts with nominal washer/nut samples; grade, threads, locking, pulley pin, straps and received stack are undefined.
// Shape is not yet fully defined. Confirm the selected item against supplier drawings or measurements, then rework this model before using it for fit, clearance or fabrication.
include <../../lib/catalog-visualizations.scad>

arbi_catalog_visualization("bolt", [12,190,19,8]);
translate([40,0,0]) arbi_catalog_visualization("bolt", [8,100,13,5.3]);
translate([0,40,0]) arbi_catalog_visualization("ring", [37,13,3]);
translate([40,40,0]) arbi_catalog_visualization("ring", [16,8.4,1.6]);
translate([0,70,0]) arbi_catalog_visualization("nut", [12,19,12]);
translate([40,70,0]) arbi_catalog_visualization("nut", [8,13,6.5]);

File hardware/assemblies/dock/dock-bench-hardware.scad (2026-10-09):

// ARBI dock-bench-hardware / DOCK-IF-01 nominal fitted bought envelopes; no supplier or load approval. / concept-unvalidated
include <../../lib/dock.scad>
dock_bench_hardware();

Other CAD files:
hardware/assemblies/dock/dock-latch-hardware.scad
hardware/assemblies/camera-pod/bulk-capacitor-1000uf.scad
hardware/assemblies/camera-pod/camera-gimbal-base.scad
hardware/assemblies/camera-pod/camera-gimbal-camera-plate.scad
hardware/assemblies/camera-pod/camera-gimbal-optical-hood.scad
hardware/assemblies/camera-pod/camera-gimbal-rain-cap.scad
hardware/assemblies/camera-pod/camera-gimbal-yoke.scad
hardware/assemblies/camera-pod/camera-pod-assembly.scad
hardware/assemblies/camera-pod/camera-pod-camera-cowl.scad
hardware/assemblies/camera-pod/camera-pod-camera-cradle.scad
hardware/assemblies/camera-pod/camera-pod-camera-hood.scad
hardware/assemblies/camera-pod/camera-pod-docking-stud.scad
hardware/assemblies/camera-pod/camera-pod-electronics-cover.scad
hardware/assemblies/camera-pod/camera-pod-electronics-deck.scad
hardware/assemblies/camera-pod/camera-pod-electronics-mount.scad
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

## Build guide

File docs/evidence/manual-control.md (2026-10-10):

# Manual control host/simulation evidence

- Date: 2026-10-11
- Work record: [#50](https://github.com/gredice/arbi/issues/50)
- Revision: source/tests in this PR; the merge commit identifies the accepted revision
- Setup: isolated Linux x86-64 host, Node 24.19.0, pinned pnpm 11.5.2, native Node SQLite,
  committed bounded plant/configuration fixtures; no deployment credentials or physical outputs
- Reviewer: automated assertions and PR review; no qualified physical reviewer

The [manual suite](../../apps/arbi-edge-controller/src/jobs/manual.test.ts) checks missing
or stale human intent, replayed/reordered packets, concurrent operator handover, retired
fences, source UTC jumps, release-before-dispatch, current capability/interlock/configuration
gates, Internet loss, changed receiver/module epochs, clock rollback, journal reopen and
attributable bounded audit handoff. Original job expiry remains 1,500 ms despite fresh
pulses. Every restart exposes no active lease and no new simulator dispatch.

Validation on this host: edge lint, typecheck and build passed; all 24 focused
manual tests passed, including SIGKILL after dispatch. The existing jobs/manual
suite passed 119 assertions, including its full crash-boundary matrix. The complete
edge suite passed 162 of 163 assertions; its existing Linux service-definition test
could not run because this host has no `/usr/bin/node` and the system directory is
not writable. That environment failure remains visible and the PR's Linux CI must
verify the service definition. Documentation links and whitespace checks passed.

The synthetic deadman is 250 ms and the virtual tick interval 50 ms. Exact-boundary
tests close the session at 1,250 ms after the accepted pulse at 1,000 ms, with zero
sample overshoot. Separate tests hold a gesture admitted but unsent, release it and
prove no later dispatch; packet retry returns the failed historical result. These
are virtual schedule and source assertions, not measured servo/motor stop latency.

Physical MCU expiry/watchdog, event-loop/kernel/device latency, selected cabinet host,
signal/wiring interfaces, storage power loss, loaded motion, independent stopping and
restraint remain unverified. The adapter still exposes `physicalActuationEnabled:false`.
Source/CI success cannot enable a physical endpoint or clear commissioning/update gates.

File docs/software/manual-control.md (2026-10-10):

# Local manual-control fencing and deadman

Work record: [#50](https://github.com/gredice/arbi/issues/50). This is an explicitly
composed, simulation-only edge slice using [cloud fenced leases](command-jobs.md),
[local jobs](local-jobs.md) and [commissioning](commissioning.md). It enables no
physical output and clears no [local safety gate](../system/local-safety-interface-matrix.md).

## Trusted composition

[ManualControl](../../apps/arbi-edge-controller/src/jobs/manual.ts) receives a trusted
local authority reader, the owning job journal and an immediate local-stop callback.
It is neither a browser endpoint nor a token verifier. The authenticated cloud/device
boundary must supply current site/realm, actor, upstream source, target boot/session,
configuration, module epochs and an exclusive cloud lease mapped conservatively into
the receiver's monotonic clock. Missing mappings/current authority inhibit admission.
Do not deserialize LocalAuthority from a client body or let a viewer request replace
the active controller's global authority. Cloud/cloud-clock uncertainty handling remains
owned by the existing command-job adapter.

Use the optional third argument to [EdgeJobs.compose](../../apps/arbi-edge-controller/src/jobs/runtime.ts)
to configure deadmanMs (50–1,000), maxJogMs (1–500), and maxLeaseMs (deadmanMs–15,000).
The returned consumer uses the gate before admission and every running phase. Its
`manual` coordinator exposes `acquire`, `pulse(sequence)`, `release`, `lost` and read-only
status. Ordinary settings never compose this coordinator or mount an actuator route.
No TLS diagnostic certificate, viewer session or UI mode grants manual capability.

## Lease and gesture rules

Only a current authenticated human with manipulation types and a matching exclusive
lease can acquire. Lease ID, holder, uint64 fence and receiver must match current trusted
state. The job journal persists a strictly increasing fence before admitting the local
session, alongside attributable audit intent/allow events. A second operator cannot
take the active session. Handover stops and retires the old session before a higher
upstream fence is accepted; source/actor/receiver/configuration/module changes stop and
retire current authority. Reconnection never silently adopts a replacement lease.

Acquisition alone cannot dispatch a gesture: it needs an increasing pulse sequence.
The authenticated gesture/renewal boundary supplies each pulse as evidence of current
human intent. It must not manufacture pulses from a transport heartbeat or server timer.
Repeated acquisition and duplicate/out-of-order pulse packets cannot renew the deadman.
Fresh accepted pulses update receiver-local time and may reflect an authorized upstream
renewal; they never extend an already admitted command's original expiry or duration.

Human direct `motion.move`/`camera.gimbal` requests require manual mode, matching session
and a fresh pulse. Maximum gesture duration is independently capped at maxJogMs; shared
configuration checks also enforce site/gimbal frames, calibrated workspace, speed and
angle limits. Ready/stationary/safe pose, current commissioning, local conditions and
module readiness are still checked by the owning job policy. Gimbal repositioning during
main movement is denied. Capture-plan orchestration and explicitly permitted autonomous
service jobs retain their separate existing local policy; this gate cannot invent
homing, maintenance, recording or a new supported command.

An exact duplicate command returns its existing logical result without dispatch or
pulse renewal, even after expiry. New stale commands/leases are rejected. A release
between command admission and dispatch is rechecked and fails the pending gesture;
release never leaves a queue that can restart motion later.

## Stop and restart behavior

The independent local consumer tick evaluates current authority and closes a session
at `min(leaseExpiry, lastAcceptedPulse + deadmanMs)`. It stops the adapter before SQLite
or audit work and marks unfinished jobs failed/operator-required. Explicit transport
teardown, revoked grants, cloud loss, changed module/receiver identity and maintenance
also stop at the next local tick; `lost` can invoke stopping immediately. Clock rollback
or unreliable local time inhibits authority. Sender UTC jumps have no effect on expiry.
The trusted loop must keep calling tick even with no active job or network callback.

For deadman D and enforced local tick interval T, the **synthetic scheduling bound** is
D + T after the last accepted pulse. Host event-loop stalls and SQLite/kernel/device
latency are not bounded by that formula. Independent Pico expiry/watchdog and physical
stopping remain required under #67 and the motion/bench gates; Linux process supervision
alone cannot enforce a real motor stopping deadline. Remote stop does not replace that
protection. The committed tests use D=250 ms and a 50 ms virtual sample interval, with
closure at the exact sampled deadline; they measure no physical stopping time.

Every startup invokes stop, drops the in-memory session, retires any durable old lease
and preserves its fence. The same/older fence cannot acquire after reopen, even with a
new transport identity. Existing journal recovery interrupts unfinished jobs and requires
fresh local reconciliation. No moving state, pulse sequence or browser gesture resumes.
Schema 2 upgrades the prior schema-1 job journal additively; old binaries reject schema 2
instead of ignoring the manual fence. Review any binary rollback with this compatibility
constraint; don't delete a journal to make an old binary start.

## Evidence and bounds

Lease start/allow/end/timeout/revoke events retain actor, site, target/source identity,
configuration/calibration and correlation. They use the existing audit vocabulary and
durable outbox/spool; pulse packets don't each allocate audit rows. The owning journal's
byte/page/record/free-space limits also bound the manual ledger. Storage or audit failure
inhibits new work, preserves visible degradation and never delays the immediate stop
callback. Retired session history remains attributable.

[Manual tests](../../apps/arbi-edge-controller/src/jobs/manual.test.ts) run in the existing
edge suite with temporary synthetic SQLite/plant fixtures. They cover missing session/pulse,
two operators, old/revoked fences, release-before-send, duplicate/reordered packets,
source clock jumps, mode/capability/calibration/interlock failures, cloud/module loss,
restart recovery, original duration and audit handoff. [Host evidence](../evidence/manual-control.md)
distinguishes these checks from physical timing and installed acceptance.

```sh
pnpm --filter @arbi/edge-controller lint
pnpm --filter @arbi/edge-controller typecheck
pnpm --filter @arbi/edge-controller test
pnpm --filter @arbi/edge-controller build
pnpm docs:check
git diff --check
```

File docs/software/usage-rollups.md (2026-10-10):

# Durable usage windows and billing-period reports

Work record: [#35](https://github.com/gredice/arbi/issues/35). This implements the
simulation-only cloud ingestion/report boundary under [ADR-0005](../decisions/0005-software-architecture-and-deployment.md),
using [accounting 1.0](mobile-data-accounting.md) and the
[device collectors](device-traffic-metering.md). [Host evidence](../evidence/usage-rollups.md)
is separate from actual SIM/router/provider reconciliation and physical acceptance.

## Installation and authority

The [server](../../apps/arbi-dashboard/src/usage/server.ts) composes current
Gredice identity, site/account resolution and the existing inventory-first PostgreSQL
transaction boundary. Explicitly install it with
[configureUsage](../../apps/arbi-dashboard/src/usage/runtime.ts). An ordinary build/start
returns a redacted 503. Branch previews never inherit this runtime. Production realms,
hardware observations and body-supplied authority are rejected.

Apply [0007-usage.sql](../../apps/arbi-dashboard/migrations/0007-usage.sql) after
0001–0004 using `pnpm --filter @arbi/dashboard db:migrate:usage` with privately supplied
`ARBI_USAGE_DATABASE_URL`. No build or startup migrates a database. The migration revokes
PUBLIC permissions; provision a separate application role with SELECT/INSERT on windows
and corrections, sequence usage and SELECT/INSERT/UPDATE on budgets, plus the existing
registry/job/audit permissions. Keep ownership and migration permissions outside that role.
Triggers deny source/correction UPDATE, DELETE and TRUNCATE, including accidental owner DML.
Privileged database owners can defeat these controls; independent backups/checkpoints
remain required. No automatic source expiry is implemented: capacity exhaustion denies
new admission rather than erasing evidence. Retention policy belongs to #36/#47.

## HTTP inputs

Mounted path: `/api/sites/:siteId/usage/:action`. All responses use `private, no-store`.

| Action | Method and authority | Input |
| --- | --- | --- |
| `device` | POST; enrolled edge Ed25519 proof, no browser Origin/Authorization | Version `arbi.usage-device/1.0`, realm, siteId, deviceId, credentialId, current identity, issuedAtMs/expiresAtMs, action `ingest`, payload and signature |
| `history` | GET; current `history.read` | Exactly linkId, fromMs, toMs; half-open UTC interval |
| `period` | POST; current `history.read` and browser-origin checks | Exactly plan (accounting MobilePlan), atMs, previousUnusedBaseBytes (decimal string or null) |
| `correct` | POST; current `configuration.write` and browser-origin checks | Exactly key, observationId, reasonId; opaque reason record identity, no private text |

Device payload is an array of 1–32 `{sequence, observation}` windows. The unsigned
envelope uses the existing [device proof](../../apps/arbi-dashboard/src/enrollment/crypto.ts)
canonical digest. Envelope validity is at most ten seconds. Source observations must
identify the same site/realm and an exact current or retained retired identity of that
enrolled collector. This permits old boot windows to upload through its current valid
credential without adopting an unknown boot. Revocation prevents all new admissions.
Intervals/observation times cannot be in the future beyond the 100 ms clock margin.

## Replay, overlap and correction

Window identities retain site, collector/interface link, boot/session, counter epoch,
layer, direction, scope, classifier and sequence. Observation ID and stream/sequence
are unique. Identical replay succeeds once; altered content or a different ID for the
same sequence conflicts. Inventory locks serialize independent processes. A batch
commits atomically; one conflict rolls back all new rows.

Boundary totals have one canonical collection point per site/link/boundary/layer/direction.
Intersecting total windows conflict even across collector boots or counter epochs;
adjacent half-open windows are accepted. Do not submit duplicate router/tunnel views.
Attributed windows conflict within the same collector/epoch/classifier/device/category
partition. Independent transfer epochs can overlap in time because concurrent attempts
carry distinct bytes. Classifier revisions remain separate comparisons and are never
added together. Ingestion must not disguise the same attempt under a new epoch.

Corrections append an invalidation linked to a durable `configuration.change` intent
and authorization in the same transaction. The correction row is the durable service
receipt; the existing audit vocabulary does not label a cloud receipt as a successful
physical configuration change. The original bytes, fingerprint and
sequence remain immutable. The reason ID names an operator-controlled explanation;
it is not a fabricated sensor measurement. A current collector can then submit a
new corrected observation/sequence. Retry of the same operator key returns the same
audit ID; conflicting keys/content fail. Audit failure rolls back the invalidation.
Search reads retain the invalidation/source history in the database; excluded observations
no longer contribute to usage. This privileged lifecycle is distinct from rewriting history.

## Reporting and uncertainty

Reports aggregate direction, boundary, layer, scope, device, category and classifier
separately, retaining exact decimal BigInt byte totals. Never add application, interface
and provider layers, or boundary totals and classified parts. LAN, relay and viewer
traffic remain separate from garden-SIM consumption. ViewerCount is never a multiplier.
Comparisons show classified and residual/unattributed bytes; over-classification is
inconsistent with a null residual. Every source window and receiver time is included
so the reported quantity can be reconstructed. Source epochs, collectors and component
coverage remain visible; freshness does not erase historical bytes.

Daily buckets explicitly use **UTC days**. Monthly periods use the supplied plan's
IANA timezone and anchor/DST policy, and disclose the runtime timezone database version.
Late reports contribute to their original day/period, not their ingestion day.
Splitting a source interval uses cumulative integer time-proportional allocation:
adjacent slices conserve every byte, and affected results are **estimated**. This does
not establish the actual traffic timing within that interval. Measured totals require
whole-window evidence. Missing windows, resets, unavailable values and unknown coverage
remain explicit; unavailable counters do not become zero. Gap output retains the first
32 ranges and indicates truncation. Application estimates never become carrier billing
truth, and even provider reports are labeled provider-reported rather than invoiced.

Plan and prior unused base are caller-supplied assumptions at this stage. Capped rollover
uses only the previous cycle's unused base once; unknown carry stays null. Remaining
allowance is unavailable for incomplete/stale chosen-layer evidence. Historical periods
stop at their end; the current period evaluates coverage only through the report time.
Settings persistence/alerts belong to #55 and local budget reservations to #45.

## Bounds and validation

Body: 60,000 bytes; batch: 32 windows; stored source: 100,000 rows/site, including
invalidated records. Queries: 35 days, 4,096 windows, 256 grouped partitions, 8 MiB report.
Requests: 120 ingestion / 60 read admissions per site/minute. Database statements time
out after 1.5 seconds, lock acquisition after one second. Exceeding a bound is an explicit
capacity error; a report never silently truncates totals. Narrow the requested interval
when a query exceeds its limit. No local stopping depends on this API or its database.

```sh
pnpm --filter @arbi/dashboard lint
pnpm --filter @arbi/dashboard typecheck
pnpm --filter @arbi/dashboard test
pnpm --filter @arbi/dashboard test:postgres
pnpm --filter @arbi/dashboard build
pnpm docs:check
git diff --check
```

The [embedded tests](../../apps/arbi-dashboard/src/usage/usage.test.ts) exercise real SQL,
but skip durable audit paths because PGlite has fsync off. The
[native suite](../../apps/arbi-dashboard/src/usage/postgres.test.ts) runs all cases plus
independent-connection concurrency and injected correction/audit rollback. These are
source/host facts, not live provider, storage-power-loss or physical validation.

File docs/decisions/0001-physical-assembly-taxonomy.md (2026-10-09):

# ADR-0001: Organize engineering information by physical assembly

- Status: Accepted
- Date: 2026-08-30

The original ownership list below is retained as the decision history.
[ADR-0010](0010-corner-support-and-winch-line-ownership.md) supersedes the
separate positioning-line root and places the winch set under the corner support
set. The physical-assembly ownership principle remains in force.

## Context

An assembly definition organized around component types such as structure, power, cabling, fasteners, printed parts, weather, and safety would mix those categories with physical assemblies such as the camera pod and dock. That makes ownership unclear: a winch cannot be assembled or validated from a “motion” list that omits its local wiring, fasteners, guard, printed drum, and maintenance evidence.

The project must support external contributors, hardware revisions, a calculated BOM, software, simulation, and a later merge into the Gredice monorepo.

## Decision

Primary engineering ownership follows real physical assemblies:

1. site installation;
2. corner station;
3. winch;
4. positioning lines;
5. camera pod;
6. dock;
7. control cabinet.

Each assembly documents its mechanical parts, electronics, cabling, connectors, fasteners, printed parts, software/firmware, environmental protection, safety controls, assembly, calibration, tests, and maintenance.

Cross-cutting concepts remain available as:

- catalog/BOM tags;
- shared conventions or standards;
- system-level interfaces and safety claims;
- queries and generated views.

They do not become owners of physical parts or quantities.

## Consequences

- A contributor can understand and build one assembly from one bounded documentation area plus shared interfaces.
- Quantities and acceptance evidence have an unambiguous owner.
- Shared parts may appear in several assembly manifests while retaining one catalog identity.
- Cables spanning assemblies require named endpoints and interface ownership rather than an orphan “cabling subsystem.”
- System-level documents are thinner and link to assembly detail.
- Cross-cutting concerns are intentionally split across the physical assemblies that own them.

## Alternatives considered

### Preserve component-type headings as primary sections

Rejected because those headings mix architecture levels and component types, and would retain the ownership problem.

### Organize solely by engineering discipline

Rejected because mechanical, electrical, software, and safety work must converge on the same physical revision and acceptance evidence.

### One monolithic design document

Rejected because it creates frequent conflicts, weak ownership, and poor navigation, while making it hard to version assembly interfaces independently.

## References

- [Documentation index](../README.md)
- [System architecture](../system/architecture.md)
- [Repository source-of-truth policy](../project/repository-source-of-truth.md)

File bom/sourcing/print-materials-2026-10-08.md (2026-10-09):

# Print material cost evidence — 8 October 2026

> Historical single-spool observation. Current prices and applicable shell selections are superseded by the [PETG Matte bulk record](petg-matte-bulk-2026-10-08.md).

The Bambu Lab EU store was inspected live on 8 October 2026 with the **Filament with spool**, **1 kg** option and quantity **1**. PLA and PETG prominently advertise the lowest bulk-sale price even at quantity one; this record uses the displayed single-spool MSRP instead. It excludes bulk, refill, coupon, membership and promotional bundle discounts.

| Material | Single 1 kg spool | Density | Price source | Density source |
| --- | ---: | ---: | --- | --- |
| Bambu Lab PLA Basic | EUR 19.99 | 1.24 g/cm³ | [EU product page](https://eu.store.bambulab.com/products/pla-basic-filament) | [TDS V3.0, p. 2](https://store.bblcdn.com/s1/default/58b85d0f3db94878854a28fdb8a0006e/Bambu_PLA_Basic_Technical_Data_Sheet.pdf) |
| Bambu Lab PETG Basic | EUR 18.99 | 1.25 g/cm³ | [EU product page](https://eu.store.bambulab.com/products/petg-basic) | [TDS V3.0, p. 2](https://store.bblcdn.com/s1/default/cb94589bf7994fdcbfa833badefae9cd/Bambu_PETG_Basic_Technical_Data_Sheet.pdf) |
| Bambu Lab ASA | EUR 24.99 | 1.05 g/cm³ | [EU product page](https://eu.store.bambulab.com/products/asa-filament) | [TDS V3.0, p. 2](https://store.bblcdn.com/ad7b08230c164e72856cffbe06bb7dc9.pdf) |

Destination: Zagreb, Croatia. These are EU displayed reference prices; the store states that price and VAT can change with destination at checkout. Croatian final VAT and shipping were not observed, so tax treatment remains unknown and no free-delivery assumption is made. No purchase is recorded. Prices are a dated observation, not a permanently current supplier fact.

The [canonical print catalog](../catalog/fabrication.json) stores spool mass, currency, observation timestamp, price basis, URLs, density and build-specific recipes. Material cost represents consumed plastic; whole-spool purchase rounding and surplus inventory are separate procurement concerns.

## Weight and kit basis

Mesh volumes come from [CAD release cad-v0.1.4](https://github.com/gredice/arbi/releases/tag/cad-v0.1.4), source commit `4e0eb44fd8df41174272569e910db93b835e51b2`. The release's OpenSCAD source hashes match this checkout. The registry metadata was subsequently refreshed when historical pod models were archived: the capture script verified the original registry in the checksum-verified source ZIP, compared every costed model's ID, revision, entrypoint, output and artifact role, and recalculated the mesh volumes. The recorded registry hash identifies the current compatible catalog; mesh hashes, release tag and source commit retain the original mesh provenance. The [capture script](../../packages/arbi-bom/scripts/capture-print-volumes.py) verifies release checksums, closed manifold edges, consistent orientation and positive signed volume. Volume in mm³ is divided by 1000 to obtain cm³, rounded to six decimal places; mass is volume × the selected material's density. Mass is rounded to three decimal places for display, after quantity extension, and cost is rounded to cents after extension. The calculator uses exact decimals for weight conversion and money.

- Camera chassis and gimbal use the current [rain-enclosure print list](../../hardware/assemblies/camera-pod/camera-pod-enclosure.md): 16 installed pieces, excluding old gimbals, dry-bench alternatives and the optional fit coupon. The owners split the current kit without overlap. Bambu PETG Basic's density is 1.25 g/cm³; earlier generic PETG mass evidence at 1.27 g/cm³ remains historical.
- The [drum print list](../../hardware/assemblies/winch/README.md#print-list) supplies three passive kits plus one powered kit, including eight flanges, eight clamp halves and thirteen pins. Four BOM drums represent that batch; fractional per-unit averages do not mean interchangeable variants.
- Each [mount kit](../../hardware/assemblies/winch/mount.md) includes two lower bearing supports, two caps, one motor stand and one coupling guard. Metal bases and installed hardware remain separate.
- The [full-cover print list](../../hardware/assemblies/winch/full-cover.md) supplies 126 installed prints across four winches, excluding four optional bench blanks. ASA is the costing selection for this exposed shell kit. Earlier/plain alternative parts are not added to the pole-routing version.
- The dock funnel and nest use their own current registered meshes, and the pulley keeper is extended across four corners.
- Optional desk feet, optional round-pole cosmetic covers and the deferred pole-pulley clamp pair have recipes and item-page comparisons but contribute nothing to the base build. Machined pole saddles are excluded from print costing. Planned dock latch, weather hood and brake have no invented geometry or zero cost.

These are **solid-volume material estimates**, not slicer output or measured weights. They include the solid CAD walls but assume fully dense material wherever CAD contains a solid. They exclude slicer supports, brims, purge and failed prints. They can substantially exceed sparse-infill consumption; thin walls can also require different slicer handling. No physical mass, strength, fit, ingress protection or safe operation is established.

PETG is the prototype costing selection for structural/functional recipes; ASA is selected for exposed covers. PLA is a price comparison. The costing choices do not alter engineering qualification or establish material suitability. Energy, depreciation/machine time and labour remain unknown rather than zero.

The camera-pod naming cleanup re-exported all 56 costed fabrication meshes with pinned OpenSCAD 2021.01 and refreshed `fabrication.json` source hashes through the capture tool. Current source hashes identify the renamed sources; `sourceCommit` is the base commit and `releaseTag` is null until a matching release is available. Model revisions, installed quantities and source-based geometry estimates remain separate from physical print evidence. Earlier release assets retain their original names.

## Registry metadata refresh, 2026-10-09

Adding approximate BOM visualization models changes the registry checksum. The
existing active and archived model entries and every previously hashed OpenSCAD
source were compared against the merged baseline after the corner-support and camera-pod naming changes and retained unchanged. Only the
`hardware/models.json` source hash in the fabrication evidence was refreshed;
mesh checksums, measured solid volumes, design revisions, recipes and price
observations remain those of the baseline's existing capture. Visualization meshes are
excluded from the print-material recipes and estimates. Generated reports were
regenerated to carry the updated input digest.

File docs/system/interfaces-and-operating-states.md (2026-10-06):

# Interfaces and operating states

## Interface policy

Every interface must name its endpoints, owner, revision, normal range, startup state, failure detection, isolation method, and acceptance test. Connector color alone is not an interface definition.

[ADR-0006](../decisions/0006-local-safety-authority-and-instrumentation.md) and the [local safety interface matrix](local-safety-interface-matrix.md) assign motion/stop authority, required observations and stage-specific evidence. They do not allocate additional GPIOs or validate circuits. Independent safeguards must survive normal-control failure; driver disable/power removal requires a reviewed restraint response, and `Parked` cannot authorize updates by itself.

## Physical interfaces

| Interface | Endpoint A | Endpoint B | Owner |
| --- | --- | --- | --- |
| Structural ground reaction | Soil / anchor | Corner post and outward guy | Site installation and corner station |
| Line routing | Corner pulley tangent | Winch drum tangent | Corner station and winch |
| Positioning load | Four line terminations | Camera-pod spider | Positioning lines and camera pod |
| Dock capture | Pod docking stud | Funnel, locating socket, and latch | Dock |
| Dock support | Dock arm | Docked corner station | Dock and corner station |
| Service mount | Winch frame | Corner-station pole face | Winch |

Exact interface drawings, tolerances, fasteners, and inspection points belong in the owning assembly revisions.

## Electrical and signal interfaces

- Fixed mains enters only the control cabinet through rated isolation and protection.
- Two baseline 48 V/350 W supplies feed fused low-voltage branches.
- Each pole receives a separately protected 48 V and return branch for its CL57Y-V20 driver.
- Each pole receives one outdoor control cable for STEP/DIR and returns, plus local home/reference wiring as designed.
- The powered winch passes 48 V through a rated slip ring and two conductors in the hybrid line.
- The pod converts 48 V to 5 V near the load and buffers short transients with approximately 1000 µF as a starting value.
- The edge service communicates locally with the Pico and pod; protocol, authentication, timeout, replay, and compatibility rules remain to be specified.

The repository's V1 Pico assignment is:

| Axis | STEP | DIR |
| --- | --- | --- |
| A | GP2 | GP3 |
| B | GP4 | GP5 |
| C | GP6 | GP7 |
| D | GP8 | GP9 |

The V1 wiring baseline routes STEP/ground on the orange pair and DIR/ground on the green pair of each outdoor Cat5e cable, with blue reserved for enable/alarm and brown spare. This is a **baseline wiring concept**, not long-run signal-integrity evidence.

## Proposed operating states

The current repository baseline describes sequences but not a complete formal state model. The following state names are proposed for implementation and simulation:

```mermaid
stateDiagram-v2
    [*] --> Boot
    Boot --> Homing
    Homing --> Ready
    Ready --> Moving: accepted job
    Moving --> Settling
    Settling --> Capturing
    Capturing --> Ready: more captures
    Capturing --> Returning: job complete
    Ready --> Returning: idle policy
    Returning --> Docking
    Docking --> Parked: latch and dock confirmation
    Parked --> Ready: release and clear dock
    Parked --> Maintenance: manual authorization and cleared area
    Maintenance --> Homing
    Boot --> Fault
    Homing --> Fault
    Ready --> Fault
    Moving --> Fault
    Settling --> Fault
    Capturing --> Fault
    Returning --> Fault
    Docking --> Fault
    Parked --> Fault
    Fault --> Homing: inspected reset
```

### State invariants

- `Moving`: gimbal remains at its safe motion pose; no normal autofocus or capture begins.
- `Settling`: Skycam trajectory is stopped; the gimbal reaches its target and waits a measured interval.
- `Capturing`: camera autofocus and capture are allowed only after settling.
- `Docking`: speed is reduced and mechanical capture is not inferred from coordinates alone.
- `Parked`: structural latch engagement and accepted dock confirmation are required.
- `Maintenance`: manually initiated only after the area is cleared; automatic logic cannot lower the pod into head space.
- `Fault`: no new normal motion is accepted; permitted recovery actions depend on the detected fault and available energy.

## Docking baseline

1. Move to PRE-DOCK approximately 0.3–0.5 m from the nest.
2. Reduce speed, initially targeting approximately 30–50 mm/s.
3. Approach while maintaining positive tension.
4. Let the funnel center the docking stud.
5. Continue until the passive latch captures it.
6. Confirm the `DOCKED` signal using a specified debounce and plausibility rule.
7. Enter `Parked` and retain only the tension needed to keep every accessible line above the accepted height.

Departure establishes normal operating tension, releases the latch, verifies release, clears the funnel, and only then resumes normal motion.

## Failure and timeout expectations

Every command must have a deadline and defined response to:

- stale or incompatible configuration;
- lost edge-to-MCU or edge-to-pod communication;
- driver alarm or encoder following error;
- home, limit, or dock sensor disagreement;
- pod undervoltage or service reset;
- failed autofocus/capture/upload;
- motion that exceeds position, time, speed, force, or tension expectations;
- loss of cloud or Internet access;
- complete or partial power loss.

The current baseline does not yet define adequate total-power-loss line-clearance behavior. This is a safety gap, not an implementation detail.

## Acceptance criteria

- State and interface schemas are versioned and tested with invalid, delayed, duplicated, and interrupted messages.
- The motion controller rejects trajectories outside its locally loaded safe envelope.
- Cloud loss does not prevent local completion, abort, docking, or fault handling.
- Dock coordinates alone can never assert `Parked`.
- Maintenance entry is authenticated or physically controlled and requires an explicitly cleared work area.
- Hardware and simulation use the same state names, units, configuration schema, and reference scenarios.

## Open questions

- What circuit and restraint sequence implements the cabinet-owned independent inhibition/isolation and Pico/pod local protections assigned in ADR-0006?
- Is the dock sensor redundant or cross-checked with motor/tension evidence?
- How is latch release actuated and proven clear?
- Which alarm and enable signals are carried on the reserved control pairs?
- What is the safe response to a single-line, driver, encoder, or powered-line failure?

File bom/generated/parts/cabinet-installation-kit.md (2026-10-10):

# Cabinet mounting and internal termination set

> Generated from canonical BOM inputs by `pnpm bom:generate`. Do not edit this page by hand.

[BOM](../../README.md) · [All items](README.md) · [Canonical part catalog](../../catalog/parts.json)

- Part ID: `cabinet-installation-kit`
- Unit: each
- Kind: component
- Lifecycle: planned
- Disciplines: electrical, mechanical, fasteners
- Traits: off-the-shelf

## Requirements

- DIN rails and supports, backplate fastening, wiring ducts and end fittings for the proposed cabinet layout. Cut lengths and actual enclosure mounting interfaces remain unselected.
- Protective-earth bar/bonding conductors and field/DC terminal blocks, wire, ferrules, lugs and labels sized by the reviewed electrical design.
- Cable entries use the existing shared cable-gland procurement assortment; reconcile the required size-level allocation before ordering. Glands are not duplicated in this set.

## Notes

One required installation set per cabinet; the layout already shows nominal rails, ducts, PE bar and terminal spaces. Previously those shapes had no BOM identity. No selected products, quote, electrical rating or installation approval is asserted.

## Used in

Quantities are per assembly definition, before build multipliers. Optional and deferred usages are shown even when excluded from a scenario. Procurement stock is not an installed physical owner.

| Assembly or purchasing bucket | Quantity | Inclusion | Usage note |
| --- | ---: | --- | --- |
| [Control cabinet](../../../docs/assemblies/control-cabinet/README.md) | 1 each | base | — |

[Canonical assembly quantities](../../assemblies/assemblies.json)

## BOM reports

- [ARBI V1 — Zagreb repository baseline](../arbi-v1-hr-zagreb.md#required-parts-by-physical-owner-or-procurement-bucket) — included.

Catalog lifecycle, procurement, and generated documentation do not establish physical validation. See the owning assembly for evidence and acceptance requirements.

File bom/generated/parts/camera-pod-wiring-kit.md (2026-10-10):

# Camera pod internal wiring and retention set

> Generated from canonical BOM inputs by `pnpm bom:generate`. Do not edit this page by hand.

[BOM](../../README.md) · [All items](README.md) · [Canonical part catalog](../../catalog/parts.json)

- Part ID: `camera-pod-wiring-kit`
- Unit: each
- Kind: component
- Lifecycle: planned
- Disciplines: electrical, electronics
- Traits: cable, off-the-shelf

## Requirements

- One 15-pin CSI ribbon between Pi 3A+ and Camera Module 3; final length, end stiffeners, bend radius and fatigue behaviour must match the compact pan/tilt route. Check whether the selected camera supply includes a usable ribbon.
- Fixed 5 V/ground distribution and two servo power/signal leads, capacitor connections and insulated incoming power termination. Connector types, conductor gauges and cut lengths remain unselected.
- One soft incoming-lead sleeve/grommet and separate soft retention for power, CSI and servo service loops; two converter ties and one capacitor tie are shown by the assembly source.
- Independent positioning-line tensile termination belongs to the winch line interface; internal conductors and connectors must carry no positioning load.

## Notes

One required assembly set per pod; component selection and exact cut lengths remain unresolved. No supplier or price selected. The long powered positioning-line conductors stay owned by winch-set; this kit covers only the pod internal terminations/harness. CSI ribbon and OEM servo leads must be reconciled with supplied accessories before purchasing.

## Used in

Quantities are per assembly definition, before build multipliers. Optional and deferred usages are shown even when excluded from a scenario. Procurement stock is not an installed physical owner.

| Assembly or purchasing bucket | Quantity | Inclusion | Usage note |
| --- | ---: | --- | --- |
| [Camera pod](../../../docs/assemblies/camera-pod/README.md) | 1 each | base | — |

[Canonical assembly quantities](../../assemblies/assemblies.json)

## BOM reports

- [ARBI V1 — Zagreb repository baseline](../arbi-v1-hr-zagreb.md#required-parts-by-physical-owner-or-procurement-bucket) — included.

Catalog lifecycle, procurement, and generated documentation do not establish physical validation. See the owning assembly for evidence and acceptance requirements.

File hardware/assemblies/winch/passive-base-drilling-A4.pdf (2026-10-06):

100 mm

## ARBI PASSIVE BASE | SHEET 1 OF 3 | 1:1

### 550 x 180 mm plate

### Print A4 landscape

### Actual size / 100%

### No fit-to-page

### Blue crosses: align

### overlapping sheets

Punch centers first;

drill pilot, then size.

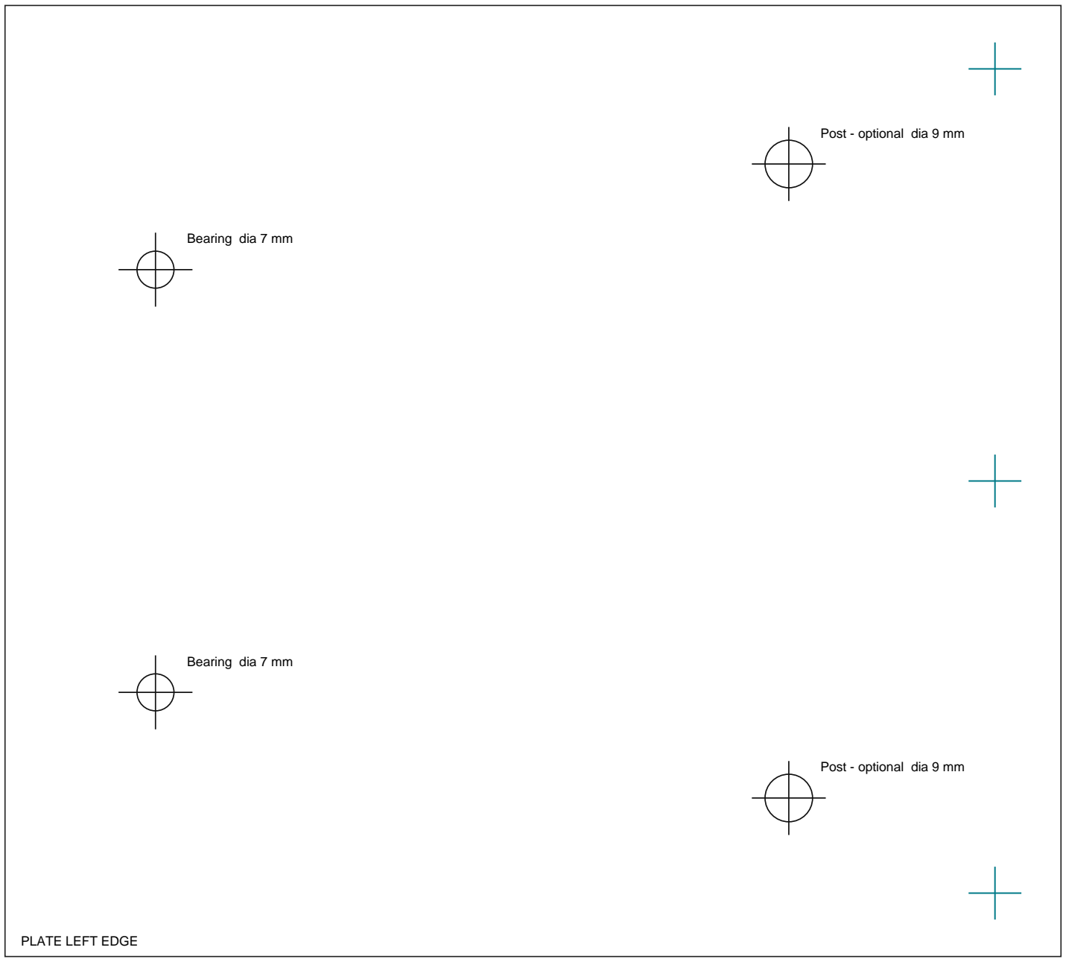
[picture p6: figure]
Bearing dia 7 mm; Post - optional dia 9 mm; PLATE LEFT EDGE

CAD: hardware/lib/winch-mount.scad | passive W=246.9 mm | all dimensions nominal

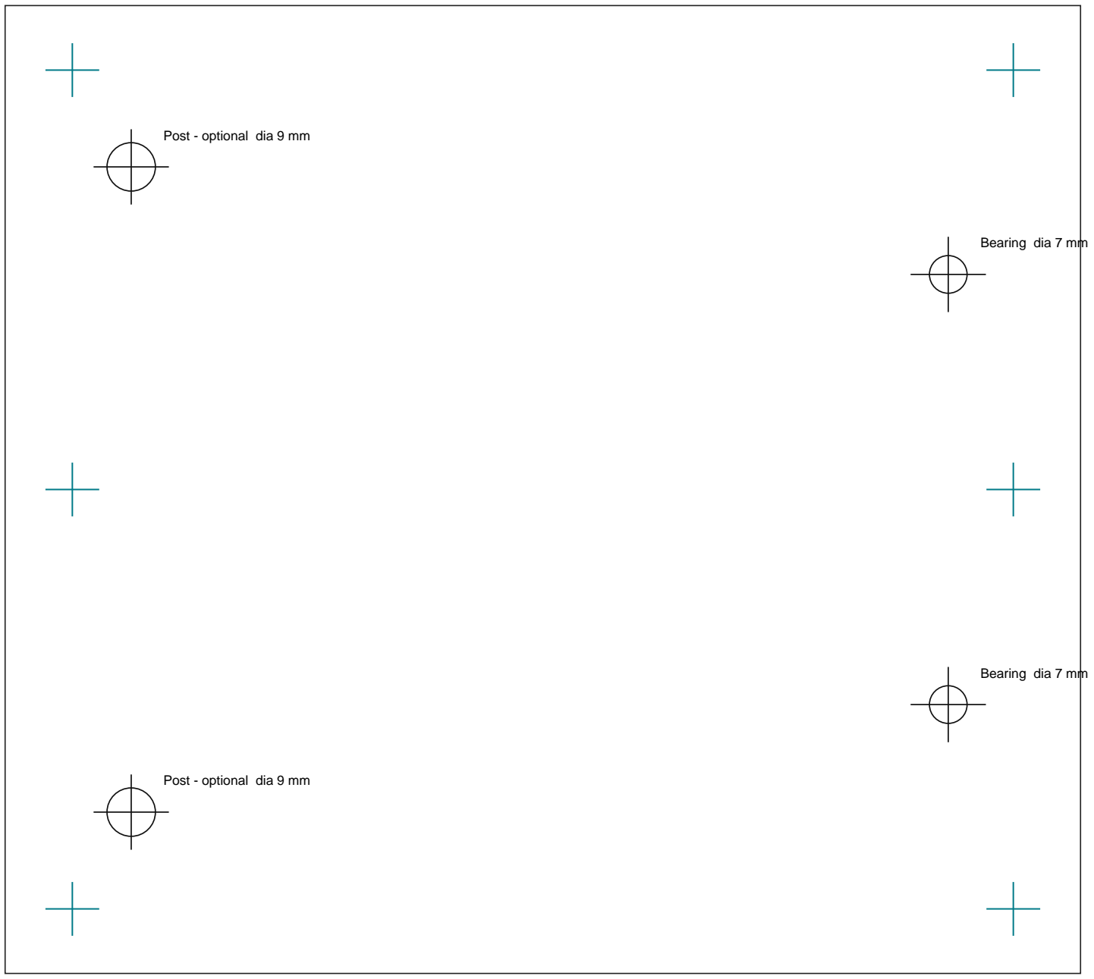
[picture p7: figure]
Bearing dia 7 mm; Post - optional dia 9 mm

100 mm

## ARBI PASSIVE BASE | SHEET 2 OF 3 | 1:1

### 550 x 180 mm plate

### Print A4 landscape

### Actual size / 100%

### No fit-to-page

### Blue crosses: align

### overlapping sheets

Punch centers first;

drill pilot, then size.

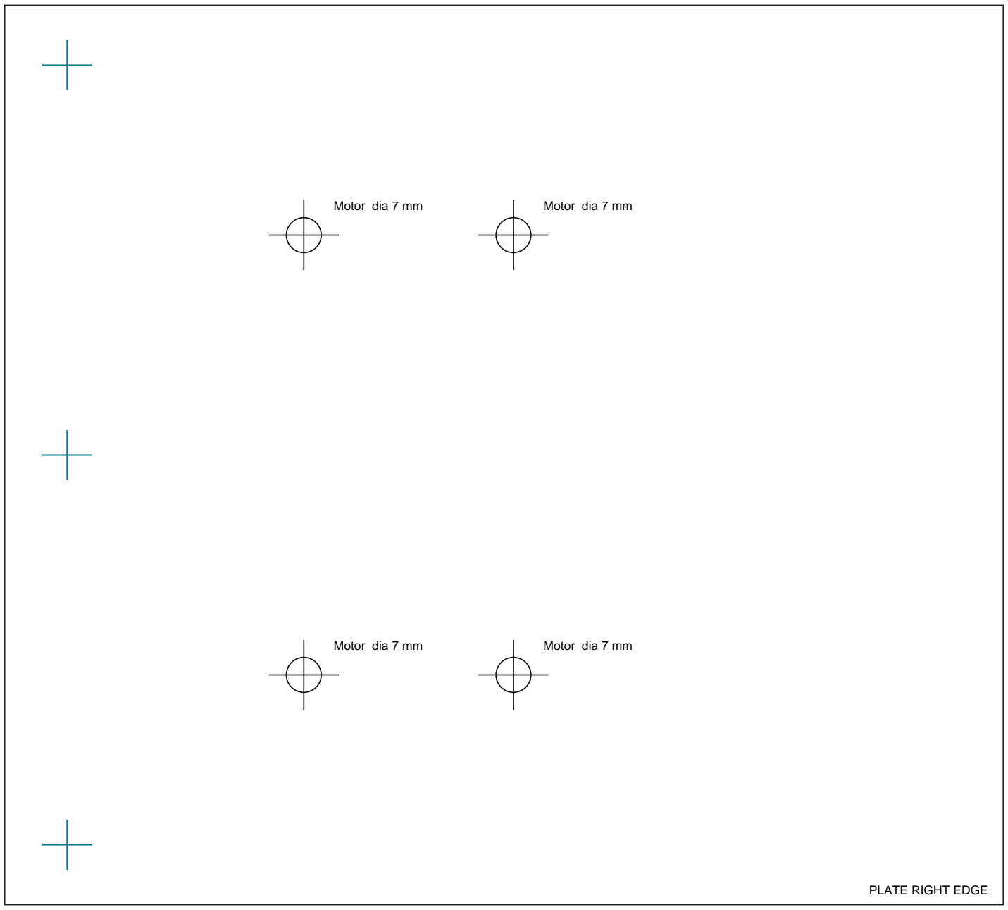
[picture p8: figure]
Motor dia 7 mm; PLATE RIGHT EDGE

100 mm

## ARBI PASSIVE BASE | SHEET 3 OF 3 | 1:1

### 550 x 180 mm plate

### Print A4 landscape

### Actual size / 100%

### No fit-to-page

### Blue crosses: align

### overlapping sheets

Punch centers first;

drill pilot, then size.

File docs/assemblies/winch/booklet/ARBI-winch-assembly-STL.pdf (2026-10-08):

ARBI WINCH & DRUM | PASSIVE / COVER KIT

# Build the actual parts

Passive-line winch: two drum sections, 340 mm shaft, 550 x 180 mm base. The passive-line winch still has a motor.

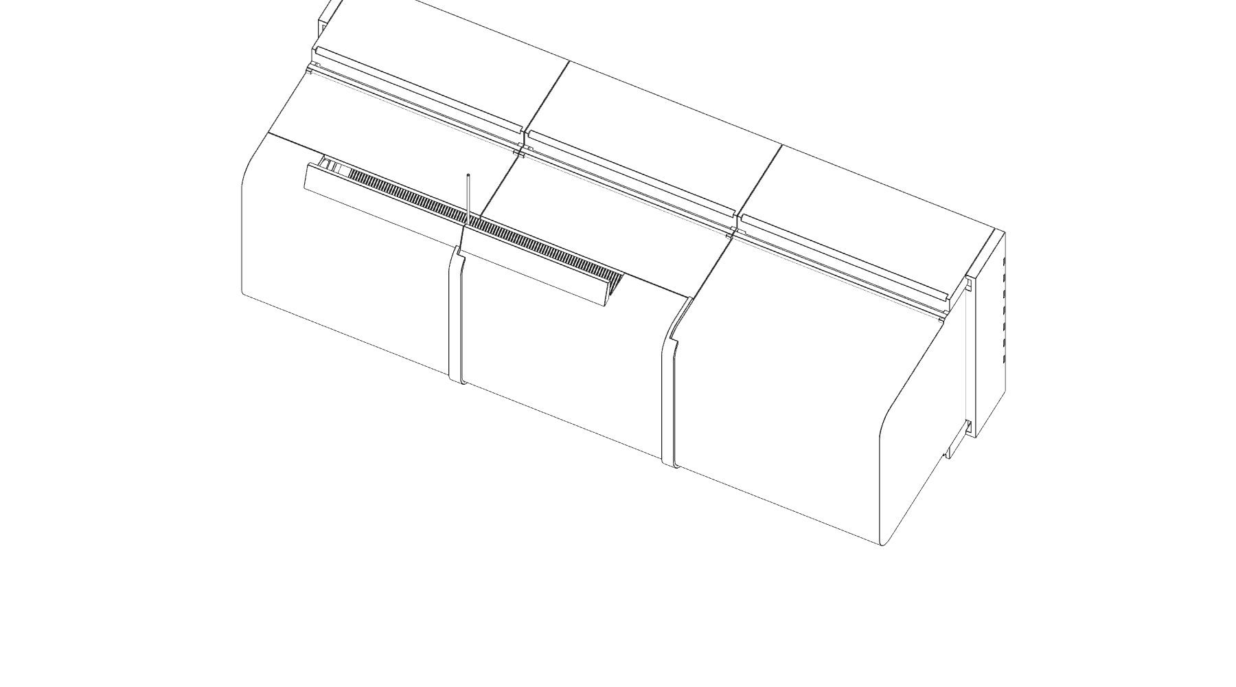
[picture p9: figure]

ARBI | Mechanical bench assembly | Revision 9 | 07 Oct 2026 | 01 / 20

## REAL GEOMETRY, STEP BY STEP

Every illustration uses the supplied STL meshes with white faces and dark outlines for assembly clarity. Part IDs identify prints; bought hardware uses labelled nominal reference models.

What is corrected
Grooved hollow drum sections and their three ribs; flat handed flanges; one alignment pin at each joint; the actual split clamp, offset bearing supports and motor stand.

Build unpowered first. This booklet covers assembly and hand-spin checks. CAD, desk feet and full cover remain concept-unvalidated. Cover installation follows on pages 15-19; loaded tests require a separate checked setup.

# 01 Printed parts

For one passive winch. Each picture is the actual STL; pictures use independent scales. Print/export file names are listed in the model pack.

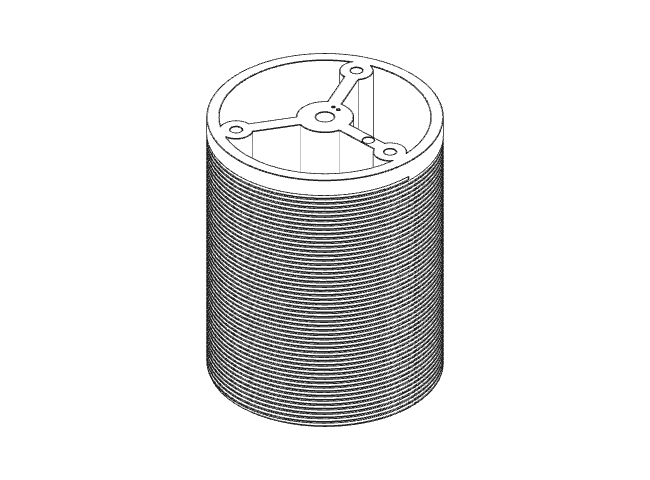
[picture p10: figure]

ARBI | Mechanical bench assembly | Revision 9 | 07 Oct 2026 | 02 / 20

P01 Passive section 1

1 x / one recessed dot

P02 Passive section 2

1 x / two recessed dots

P03 Left flange

1 x

P04 Right flange

1 x / handed part

P05 Shaft clamp half

2 x / identical prints

P06 Line tail clamp

1 x / two underside channels

P07 Alignment pin

3 x / one per joint

P08 Bearing lower

2 x / feet face outward

P09 Bearing cap

2 x

P10 Motor stand

1 x

P11 Coupling cover

1 x / revision 0.1.1

Desk feet are optional
Two short + two long.
See page 13.

Powered drum sections are in the ZIP, but are not used here.

Deburr holes, locating sockets and mating faces. Dry-fit the shaft and bearings. The drum groove must stay continuous across the middle joint.

# 02 Bought parts

Reference STLs describe the hardware for these illustrations. They are not printed replacements for bearings, shafts, fasteners, the motor or coupling.

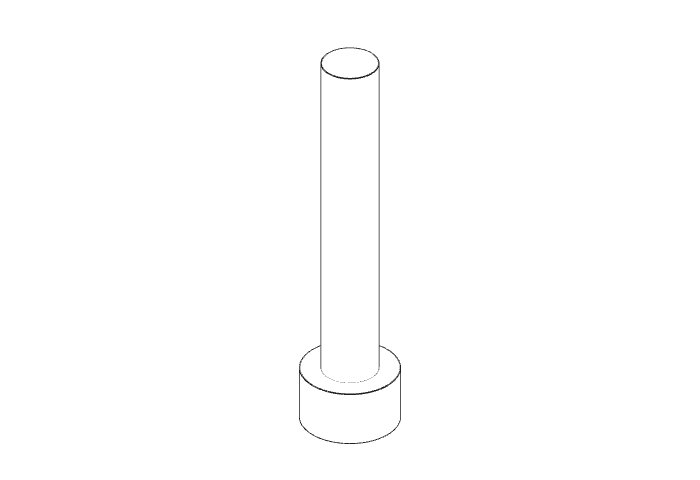
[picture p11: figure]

ARBI | Mechanical bench assembly | Revision 9 | 07 Oct 2026 | 03 / 20

H01 Motor

1 x / 23HS40 reference

H02 608 bearing

2 x / 8 x 22 x 7 mm

H03 Inner-ring spacer

2 x / 8.2 ID, 11 OD, 2 thick

H04 Shaft collar

2 x / 8 mm bore

H05 Jaw coupling

1 set / two hubs + spider

H06 Drum shaft

1 x / dia 8, nominal 340 mm

H07 Drum tie rods

3 x / M5, nominal 280 mm

H08 Aluminium plate

1 x / 550 x 180 x 8 mm

H09 Fasteners

See complete table, page 14

The motor body/shaft envelope follows the supplier specification. Mounting pitch and pilot, collar outline and coupling internals are nominal. Match the received hardware before tightening.

Keep steel spacers on the bearing inner rings. Ordinary large washers may rub bearing seals or the housing. M5 nuts inside the bearing lowers must be plain nuts, not tall nylocs.

# 03 Key the drum sections

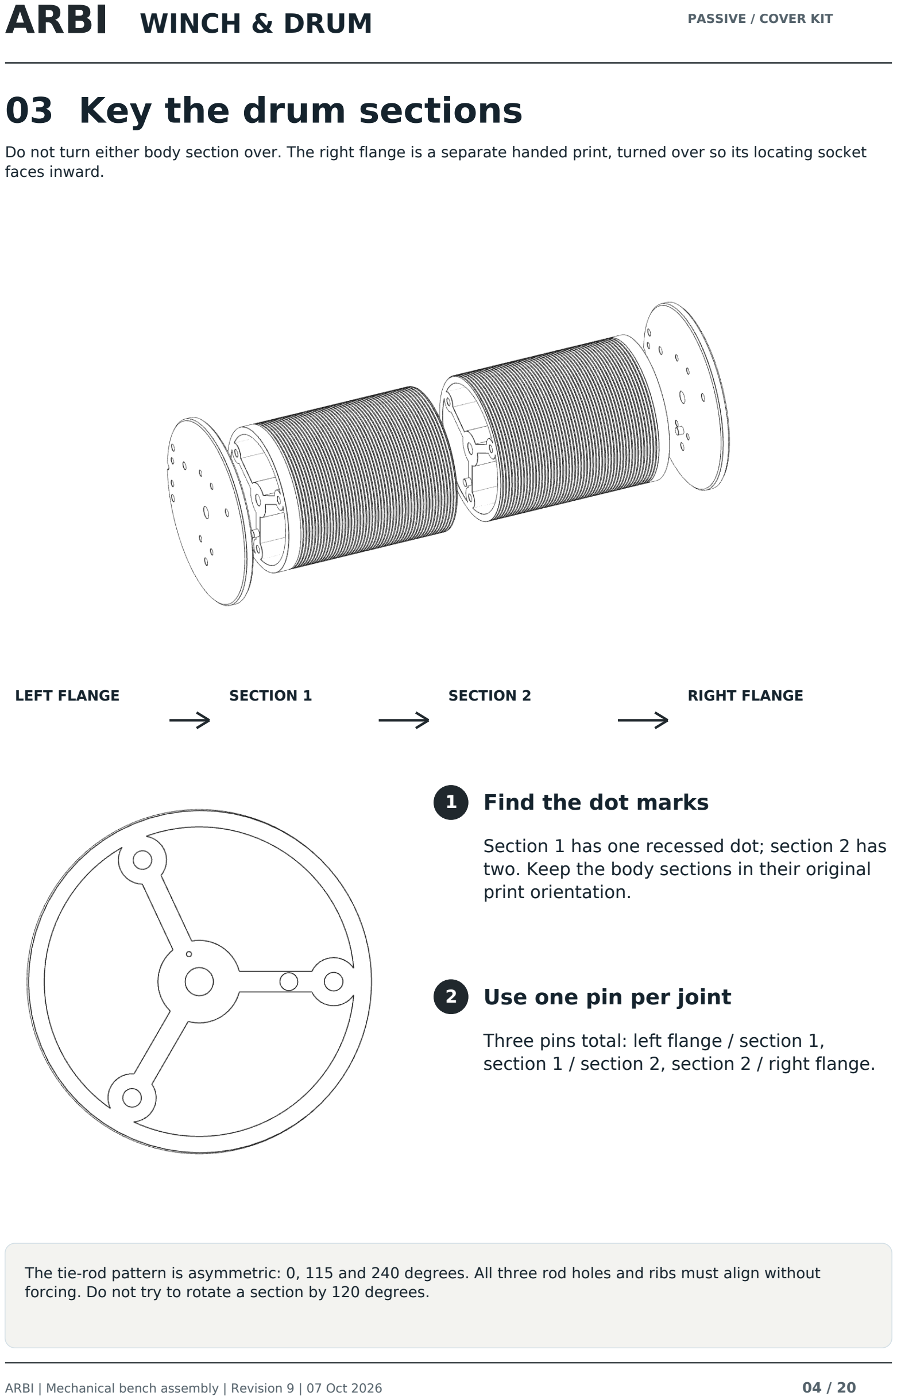
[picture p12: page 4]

Do not turn either body section over. The right flange is a separate handed print, turned over so its locating socket faces inward.

ARBI | Mechanical bench assembly | Revision 9 | 07 Oct 2026 | 04 / 20
LEFT FLANGE | SECTION 1 | SECTION 2 | RIGHT FLANGE

## 1 Find the dot marks

Section 1 has one recessed dot; section 2 has two. Keep the body sections in their original print orientation.

## 2 Use one pin per joint

Three pins total: left flange / section 1, section 1 / section 2, section 2 / right flange.

The tie-rod pattern is asymmetric: 0, 115 and 240 degrees. All three rod holes and ribs must align without forcing. Do not try to rotate a section by 120 degrees.

# 04 Close and tie the drum

Keep the end faces flush. Tighten the three tie rods progressively, alternating between them.

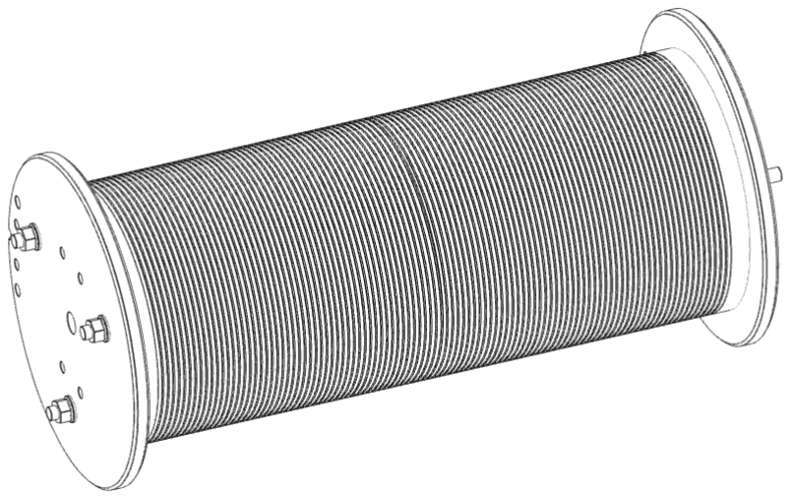
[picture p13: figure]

ARBI | Mechanical bench assembly | Revision 9 | 07 Oct 2026 | 05 / 20

## 1 Preload four clamp-foot screws

Before closing the drum, feed four M4 x 25 screws and washers through the right flange from its inside face. Their shafts point outward toward the split clamp.

### 4 x M4 x 25 + 4 washers, inserted before closing

## 2 Fit the tie rods

Pass three M5 x 280 rods through the complete stack. Put one M5 washer and one M5 locknut at each end: six washers and six nuts total.

Faces should close flush without crushing the prints. No validated tightening torque is specified. Recheck the groove seam and all three joints before fitting the shaft clamp.

# 05 Clamp the shaft

The clamp is two identical rectangular halves. Rotate the second half 180 degrees around the shaft; do not substitute a single collar.

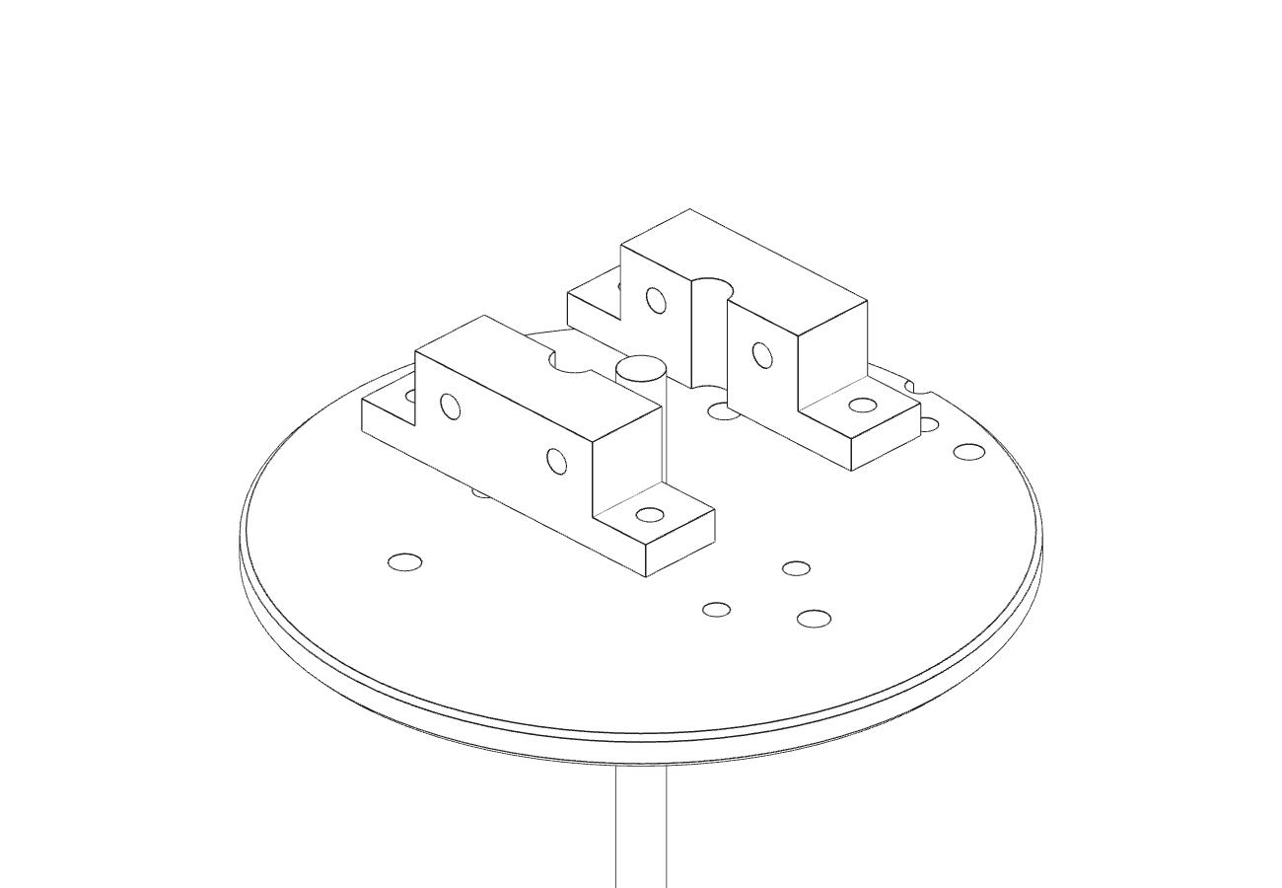
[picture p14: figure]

ARBI | Mechanical bench assembly | Revision 9 | 07 Oct 2026 | 06 / 20
BRING THE TWO HALVES TOGETHER | CLAMP FIRST, FEET SECOND

## 1 Slide in the 8 mm shaft

Pass the shaft through the drum and leave it movable while fitting the two clamp halves onto the four preloaded flange screws.

## 2 Tighten the cross-bolts first

Use two M4 x 45 bolts, four washers and two metal locknuts. Tighten evenly to grip the shaft. Keep the designed split gap; do not force the halves fully shut.

Then secure the four clamp feet with four additional M4 washers and four locknuts. The shaft continues out of view in these close-ups.

For the 340 mm shaft, start with about 27 mm projecting beyond the non-motor flange; verify final coupling engagement on page 10. Fit the tail clamp on page 11.

# 06 Prepare the base supports

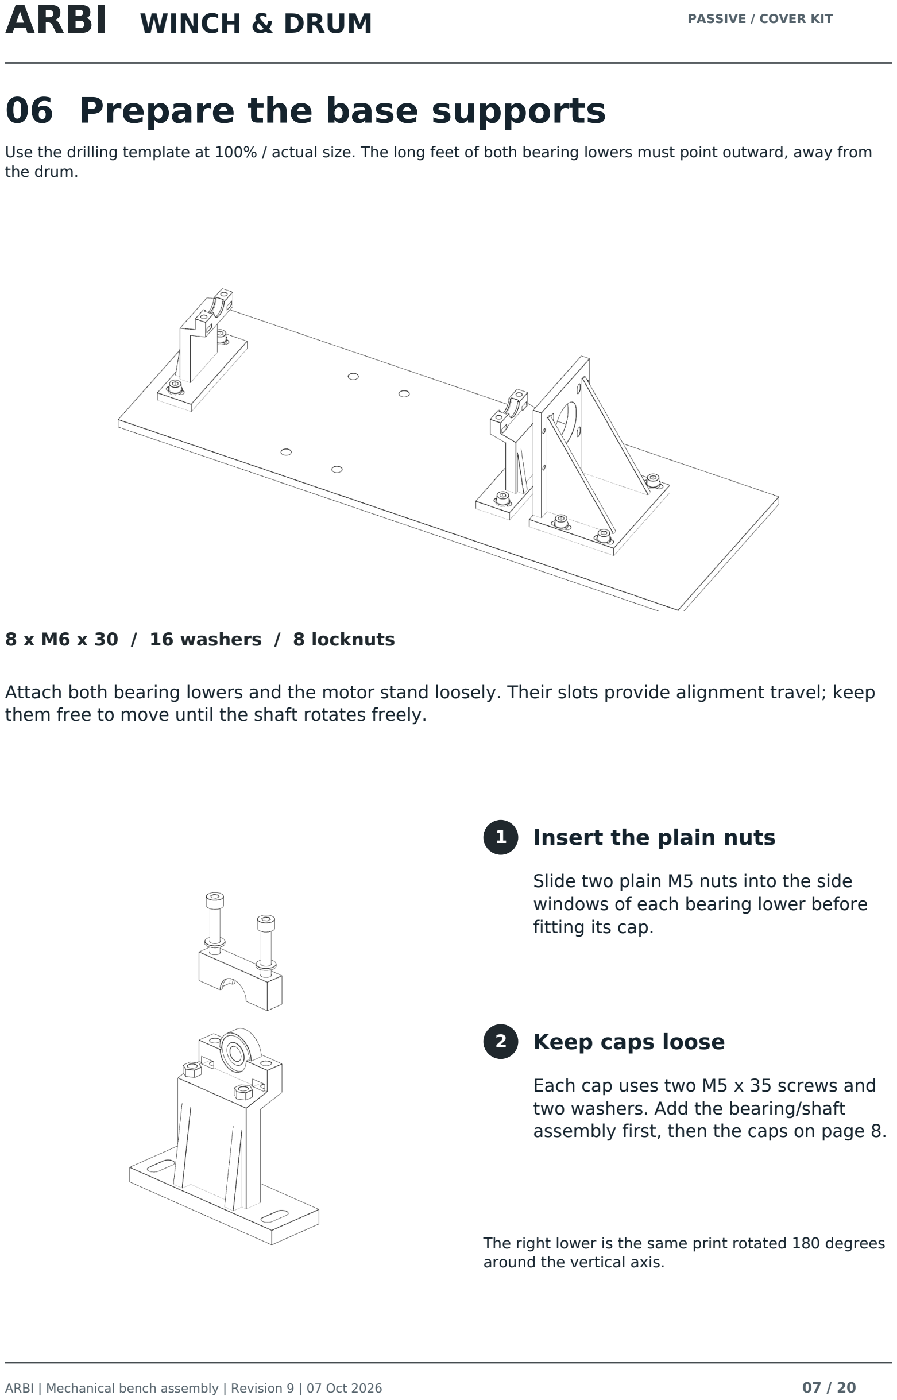
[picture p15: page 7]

Use the drilling template at 100% / actual size. The long feet of both bearing lowers must point outward, away from the drum.

ARBI | Mechanical bench assembly | Revision 9 | 07 Oct 2026 | 07 / 20

### 8 x M6 x 30 / 16 washers / 8 locknuts

Attach both bearing lowers and the motor stand loosely. Their slots provide alignment travel; keep them free to move until the shaft rotates freely.

## 1 Insert the plain nuts

Slide two plain M5 nuts into the side windows of each bearing lower before fitting its cap.

## 2 Keep caps loose

Each cap uses two M5 x 35 screws and two washers. Add the bearing/shaft assembly first, then the caps on page 8.

The right lower is the same print rotated 180 degrees around the vertical axis.

# 07 Place the shaft assembly

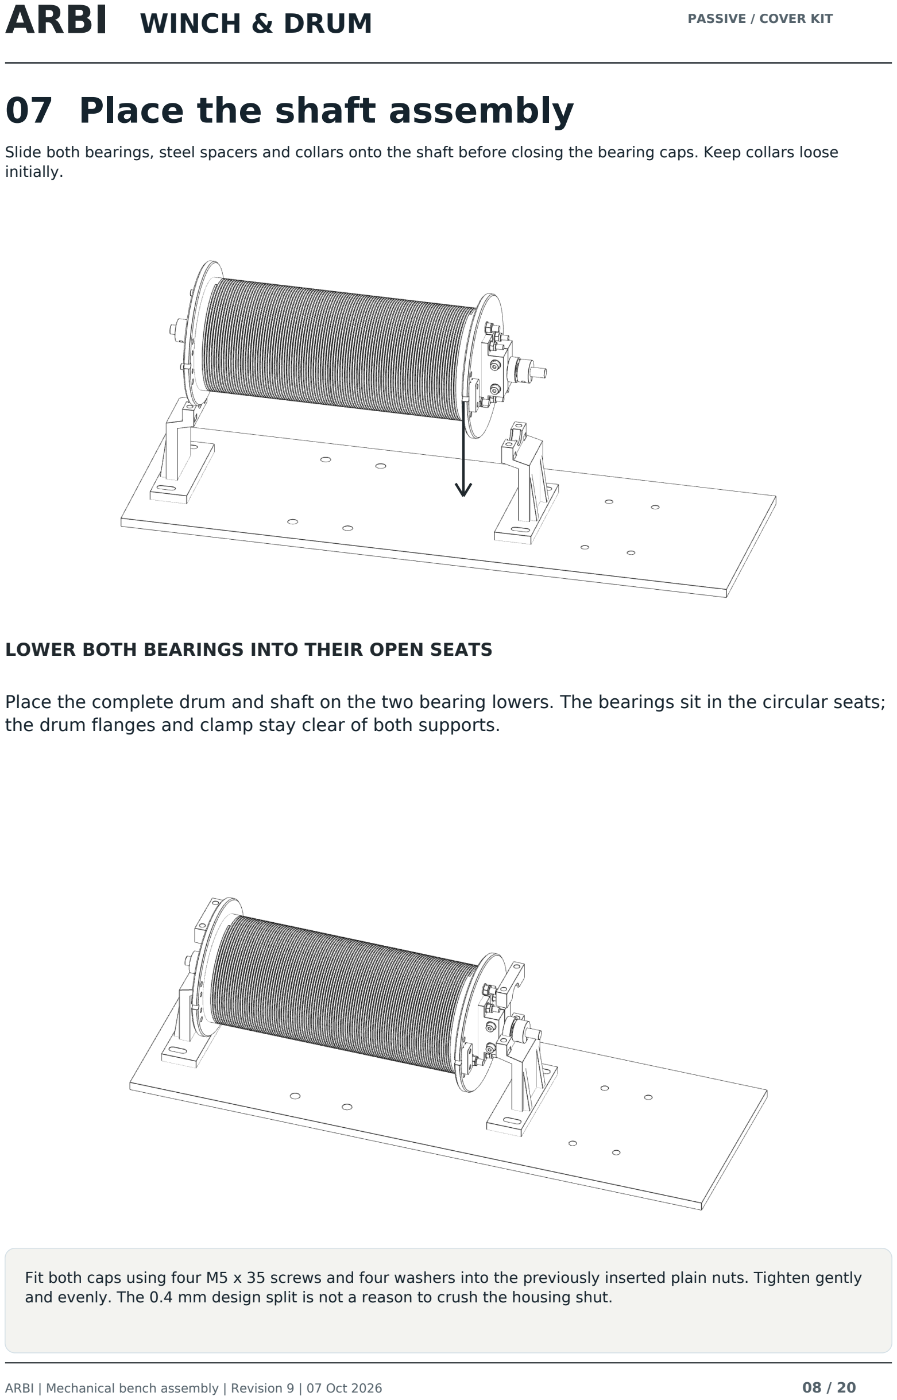
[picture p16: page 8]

Slide both bearings, steel spacers and collars onto the shaft before closing the bearing caps. Keep collars loose initially.

ARBI | Mechanical bench assembly | Revision 9 | 07 Oct 2026 | 08 / 20

LOWER BOTH BEARINGS INTO THEIR OPEN SEATS

Place the complete drum and shaft on the two bearing lowers. The bearings sit in the circular seats; the drum flanges and clamp stay clear of both supports.

Fit both caps using four M5 x 35 screws and four washers into the previously inserted plain nuts. Tighten gently and evenly. The 0.4 mm design split is not a reason to crush the housing shut.

# 08 Set collars and alignment

Spacers and collars sit outside the two bearings, away from the drum. Leave slight axial freedom; do not preload the bearings.

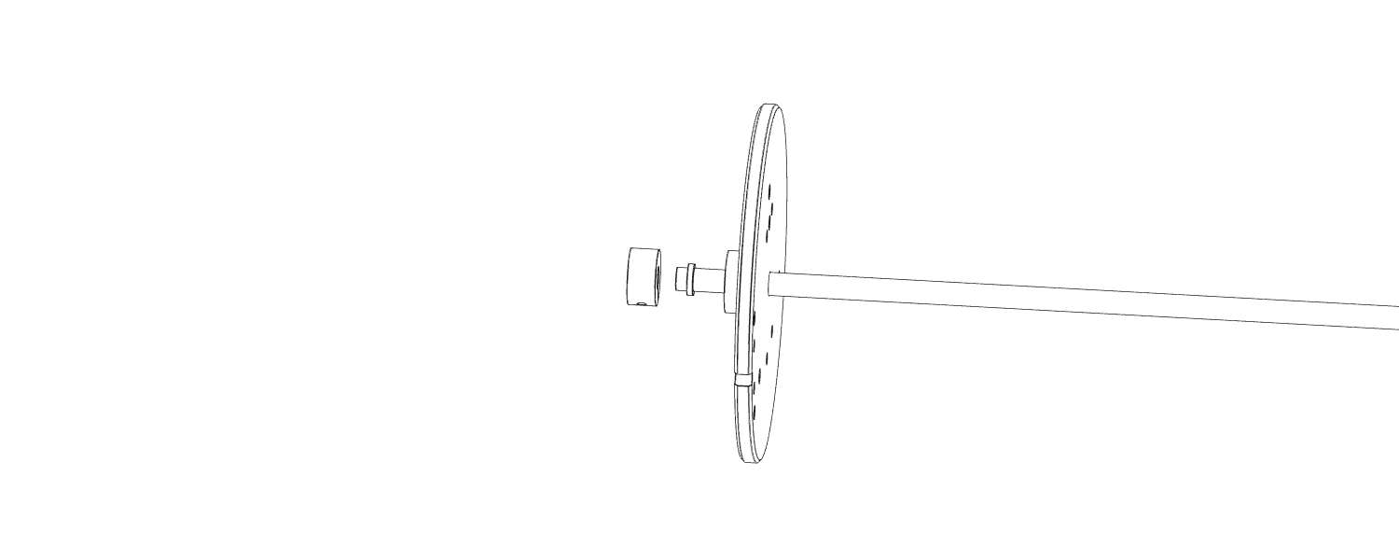
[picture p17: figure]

ARBI | Mechanical bench assembly | Revision 9 | 07 Oct 2026 | 09 / 20

NON-MOTOR END: collar > spacer > bearing > flange

The thin spacer must contact only the bearing inner ring. Keep its outer edge clear of the bearing seal and printed housing. The collar locks to the shaft; it must not clamp the housing.

MOTOR END
Drum / split shaft clamp > bearing > 2 mm spacer > shaft collar > coupling.

## 1 Align the bearing lowers

Turn the shaft by hand while adjusting the M6 slots. Tighten base bolts progressively and check rotation again after each adjustment.

Stop if you feel scraping, binding or a notchy bearing. Reposition the support or collar before continuing.

# 09 Align motor and coupling

Install the motor with its shaft toward the drum. The coupling connects aligned shafts; do not use it to pull misaligned mounts together.

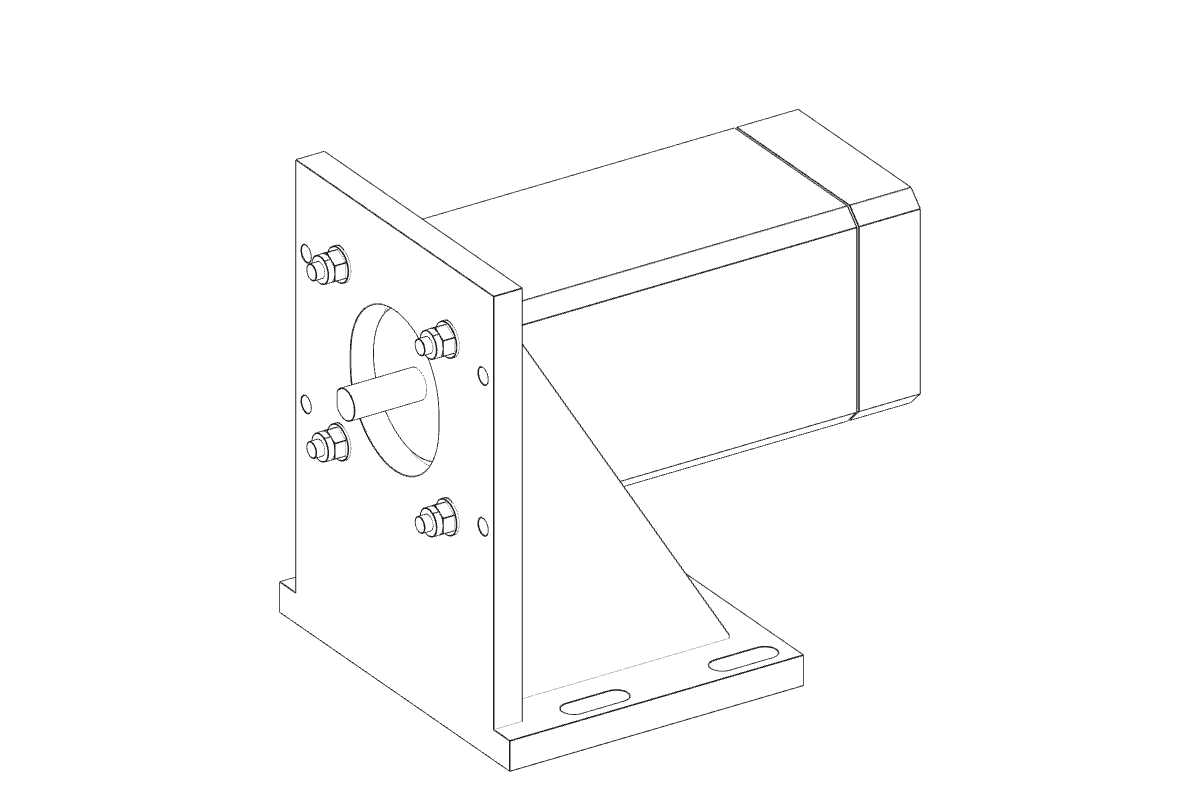
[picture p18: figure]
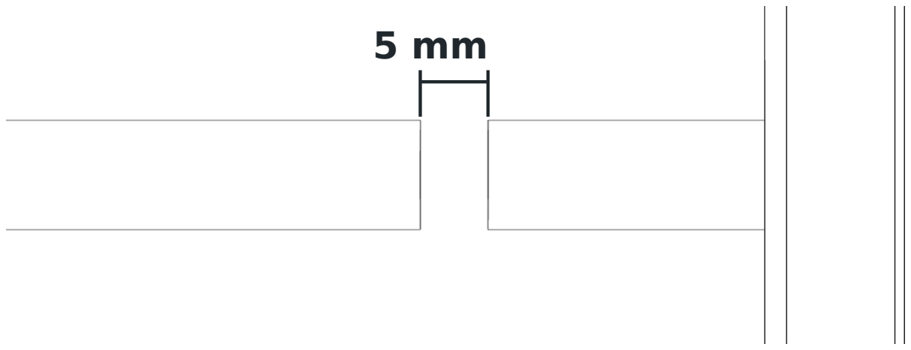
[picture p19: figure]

ARBI | Mechanical bench assembly | Revision 9 | 07 Oct 2026 | 10 / 20

Motor mounting
Fit four fasteners matched to the received motor flange. M4 x 25 is only the repository allowance; verify hole type and engagement.

Coupling
Place one hub on each shaft and the elastomer spider between them. Seat and lock the hubs according to the actual coupling.

Nominal CAD setup: about 10 mm shaft engagement at each coupling end, leaving 5 mm between shaft tips. Verify actual hub/spider geometry. The shaft tips must not touch.

# 10 Secure the line tail

Fit the tail clamp on the outside of the right flange. It grips two bare Dyneema legs in its underside channels.

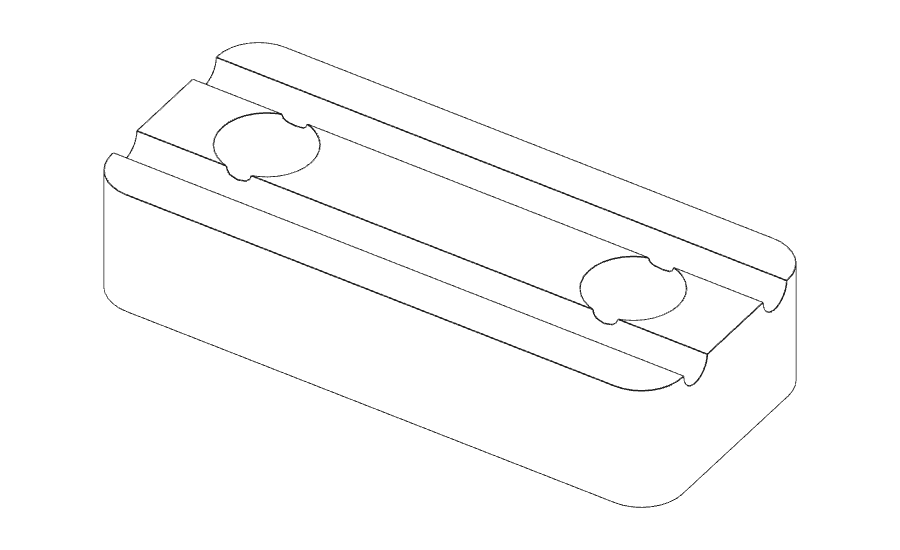
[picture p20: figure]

ARBI | Mechanical bench assembly | Revision 9 | 07 Oct 2026 | 11 / 20

Route over the end margin and through the rim notch, then double back through both clamp channels. The silver overlay shows the two legs and return loop; the clamp is moved aside to show its underside.

Use two M4 x 25 screws, four washers and two locknuts. Smooth the notch and channels. Keep at least three reserve wraps on the drum at maximum payout.

The two shallow channels on the clamp underside carry the outgoing and returning bare line. Keep the line clear of screw holes.

Finish the line termination and confirm free hand rotation before fitting the revised coupling cover on the next page.

# 11 Fit the revised coupling cover

Reprint P11 only: winch-coupling-guard-r0.1.1.stl. The existing motor stand and its four cover mounting holes remain compatible.

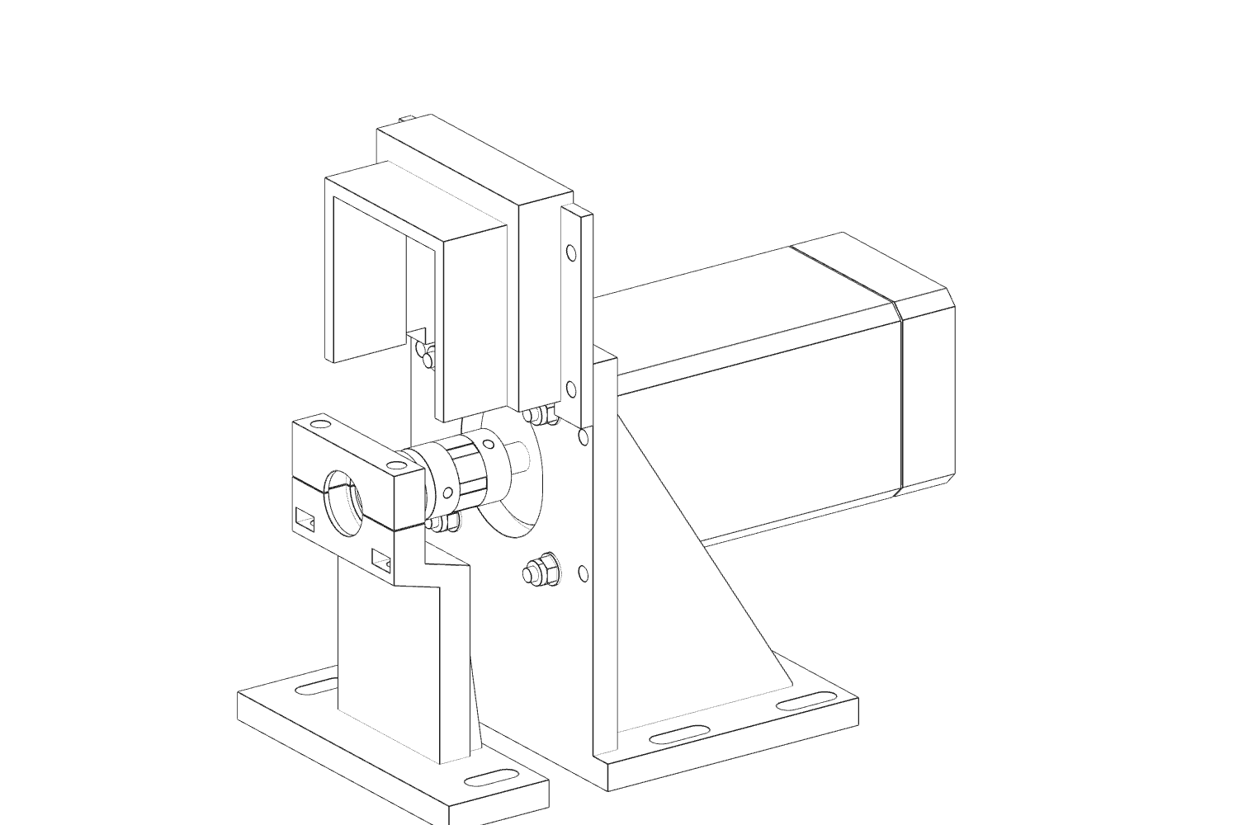
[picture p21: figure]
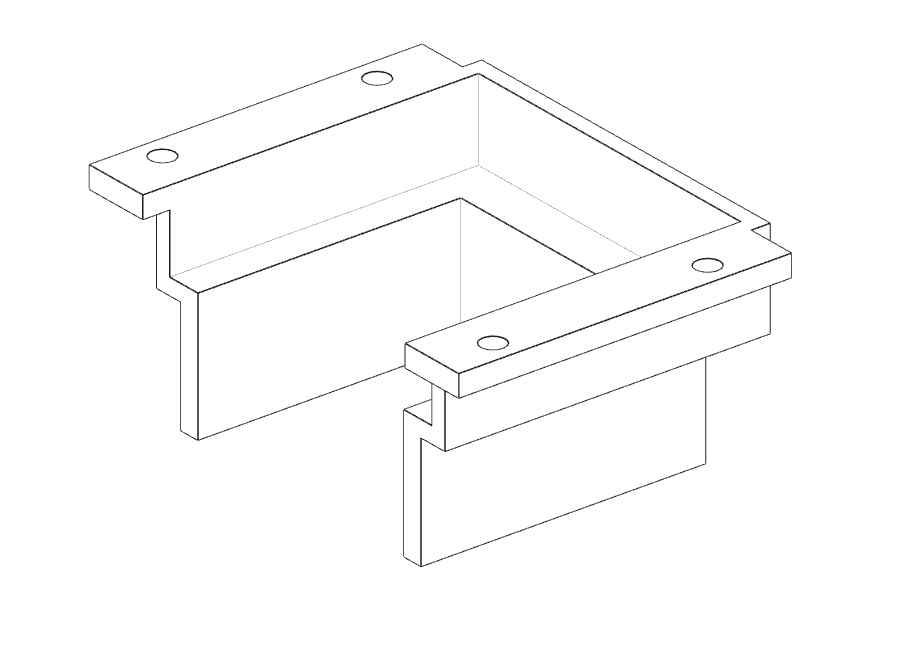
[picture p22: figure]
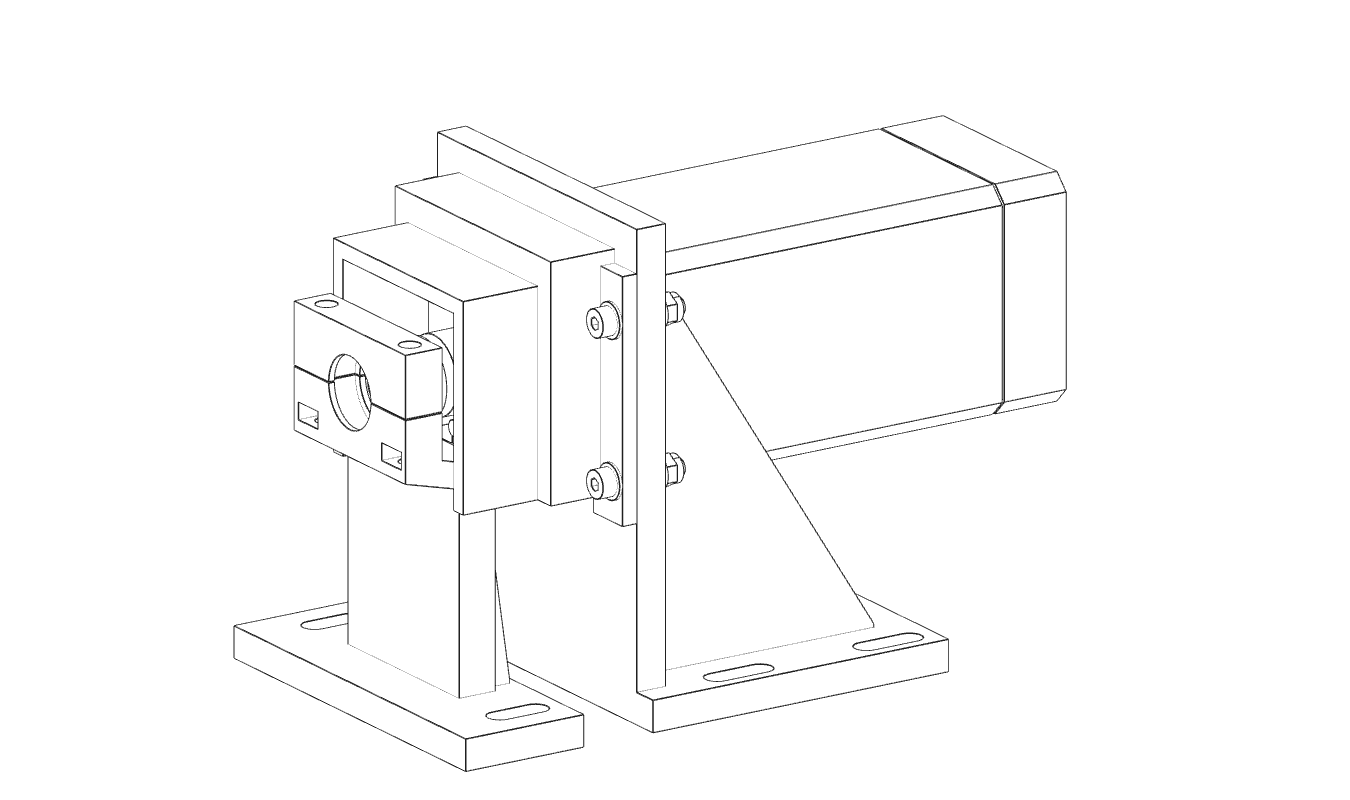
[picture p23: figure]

ARBI | Mechanical bench assembly | Revision 9 | 07 Oct 2026 | 12 / 20

WIDER MOTOR END CLEARS THE FOUR FASTENER STACKS

Tighten and align the motor first. Lower the cover over the coupling with its open underside downward; the widened end faces the motor stand. The drawing includes representative motor screws, washers and nuts.

Check your hardware: maximum 12 mm across each motor fastener stack and 14 mm projection from the coupling-side stand face, including screw tips. The recess adds 1 mm clearance and allows the full +/-2 mm vertical slot adjustment.

Use four M4 x 20 cover screws, eight 9 mm OD washers and four locknuts. Seat the flange without force. The revised print still needs a physical fit check.

# 12 Desk feet and final checks

Optional desk setup for the passive base. The four existing post holes take the feet; there are no new holes to drill.

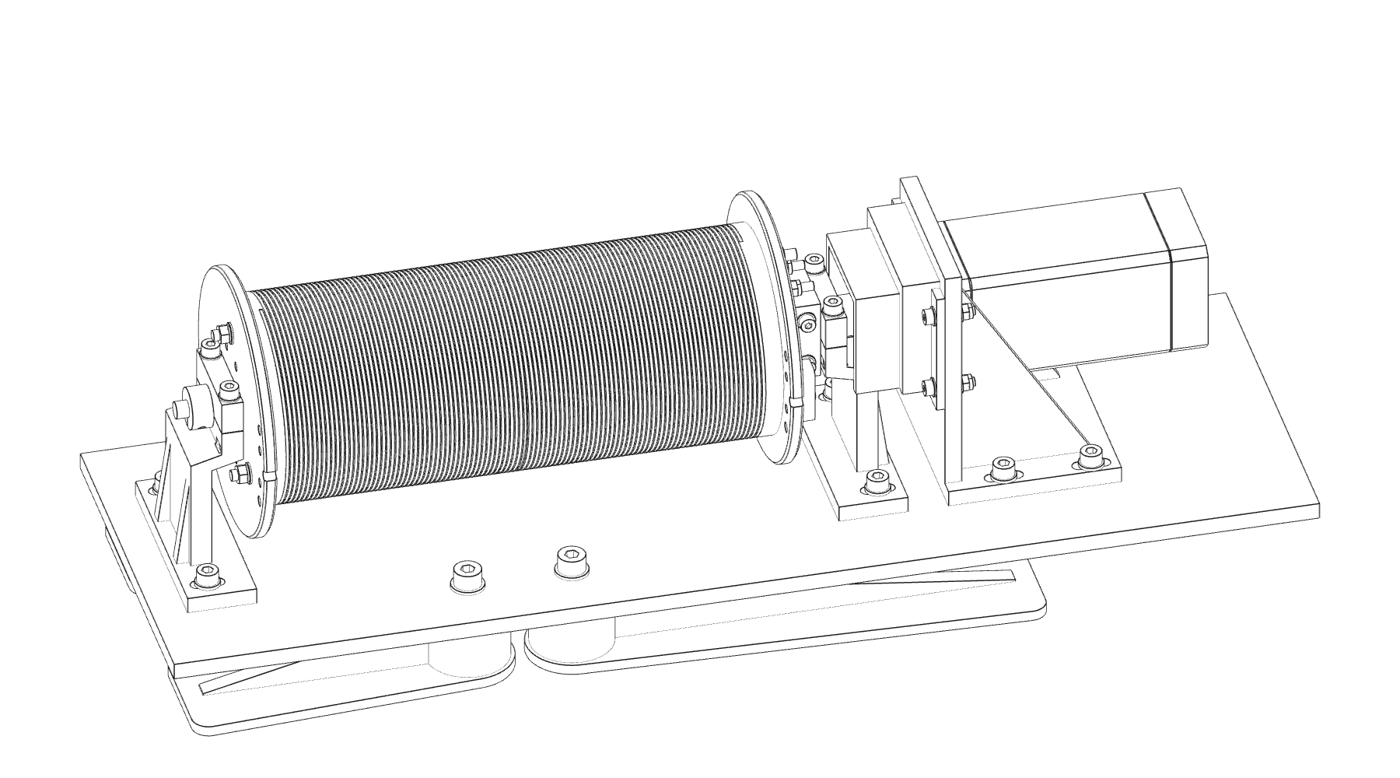
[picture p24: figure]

ARBI | Mechanical bench assembly | Revision 9 | 07 Oct 2026 | 13 / 20

### 2 SHORT FEET: away from motor

### 2 LONG FEET: toward motor

Use four M8 x 35 bolts, eight standard washers and four M8 locknuts on the 8 mm plate. Recess the nuts inside the feet. Plate underside is 35 mm above the desk; existing screws may protrude at most 25 mm.

All drum joints close flush; the groove is continuous.

Shaft turns freely; collars do not preload bearings.

Rods, nuts, flanges and clamp clear the supports through a full turn.

Motor shafts align; coupling has axial clearance; all feet sit flat.

Complete these checks unpowered. Desk feet are not anchors for loaded cable tests.

# 13 Fasteners and model notes

Quantities below are for one passive winch. Nuts and washers are additional to the bolts or rods listed.

ARBI | Mechanical bench assembly | Revision 9 | 07 Oct 2026 | 14 / 20
Location | Bolts / rods | Washers | Nuts
Drum tie rods | 3 x M5 x 280 | 6 x M5 | 6 x M5 lock
Clamp feet to flange | 4 x M4 x 25 | 8 x M4 | 4 x M4 lock
Clamp cross-bolts | 2 x M4 x 45 | 4 x M4 | 2 x M4 lock
Line tail clamp | 2 x M4 x 25 | 4 x M4 | 2 x M4 lock
Bearing caps | 4 x M5 x 35 | 4 x M5 | 4 x M5 plain
Base supports + stand | 8 x M6 x 30 | 16 x M6 | 8 x M6 lock
Coupling cover | 4 x M4 x 20 | 8 x M4 | 4 x M4 lock
Motor to stand | 4, match actual motor | As required | As required
Optional desk feet | 4 x M8 x 35 | 8 x M8 | 4 x M8 lock

## MODEL PACK: 86 STL FILES

42 ARBI fabrication meshes: custom prints and the two machined-metal saddle shapes. Bottom-layout replacements: passive left/right and powered right r0.3.0, powered pole middle and lower pole fascia r0.1.0. Reuse the other parts. Do not print metal saddles.

44 reference meshes cover bought hardware and the metal base plates. Their simplified threads, bearing internals, motor mounting details and coupling teeth are illustrative. They are not supplier-certified models or manufacturing replacements.

The source, STL hashes, dimensions and a manifest of every illustrated component are included. All exported meshes were checked for closed surfaces, consistent winding and positive volume. Geometry checks do not establish print fit or load capacity.

Source references
ARBI: github.com/gredice/arbi. Exact source files and SHA-256 hashes are included; see source-provenance.json. Motor: StepperOnline kit 4-CLYS30-V20, model 23HS40-5004D-E1000. (https://github.com/gredice/arbi) Supplier body/shaft dimensions checked 27 Sep 2026; supplier STEP download was unavailable. (https://github.com/gredice/arbi)

Powered-model STLs are included for completeness. This booklet assembles the passive-line version only; the longer powered base/shaft needs separate validation.

# 14 Full assembly cover

Full-cover kit r0.3.0 under ADR-0007. Reuse the drivetrain and r0.1.1 coupling guard. Drill the extra base holes before fitting clips.

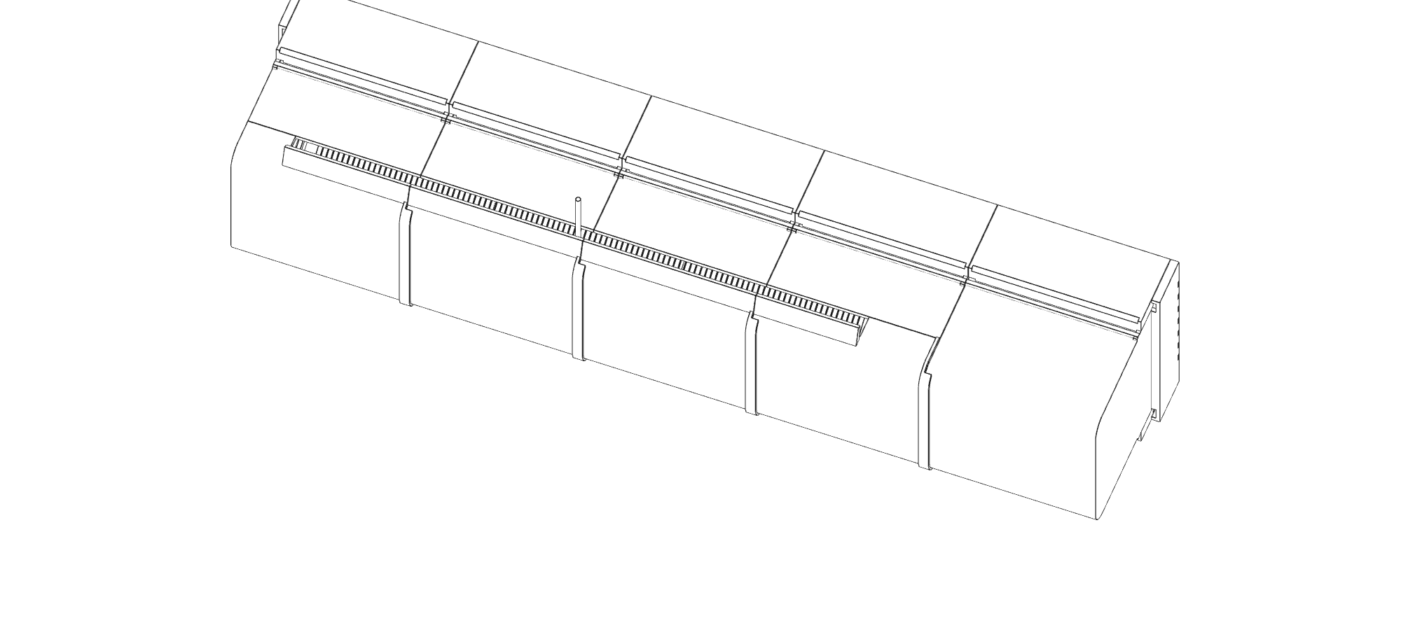
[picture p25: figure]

ARBI | Mechanical bench assembly | Revision 9 | 07 Oct 2026 | 15 / 20

PASSIVE: 3 MAIN PANELS + 2 PAYOUT SHUTTERS

POWERED: 5 MAIN PANELS + 4 PAYOUT SHUTTERS

Added print | Passive | Powered
Left / middle / right main panels | 1 / 1 / 1 | 1 / 2* / 1
Distinct powered transition, index 3 | 0 | 1
Identical variant payout shutters | 2 | 4
Identical dark base clips | 12 | 20
Fixed-loom base anchor | 1 | 1

Main panels print on an axial seam; shutters on their outer face; clips and anchor on their base feet. Powered index 3 needs its own transition print: the slot stops at X=580.3 mm. Use the pole middle at index 1 and plain middle at index 2; never use a third middle. All cover prints start at print Z=0 and fit inside 240 mm per axis; inspect supports.

# 15 Clips, holes and fasteners

New holes only: keep all original bearing, motor-stand and post patterns. Base blanks stay 550 / 880 x 180 x 8 mm.

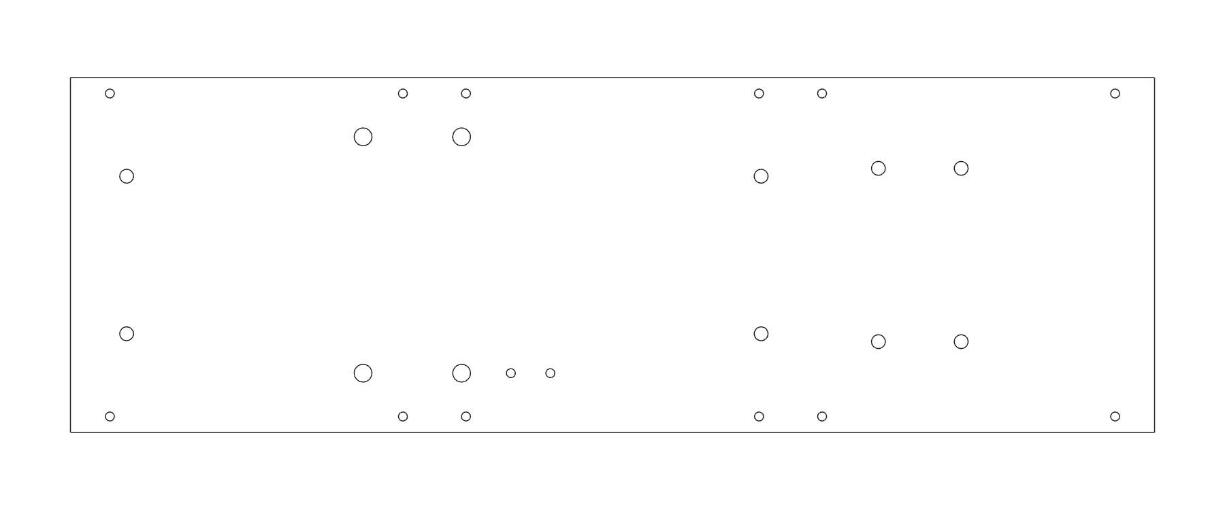
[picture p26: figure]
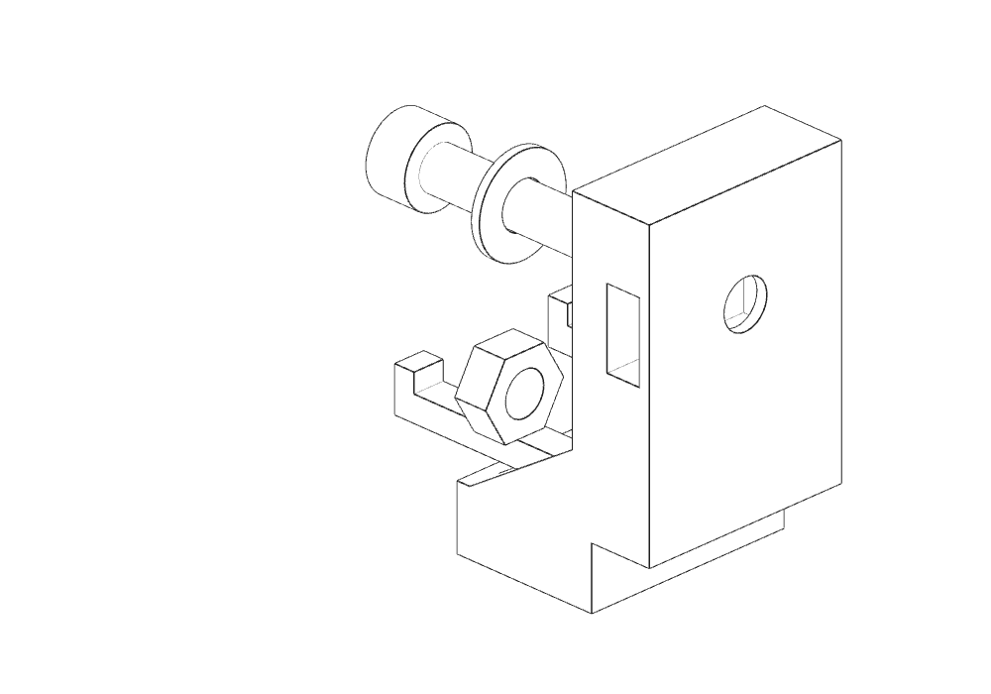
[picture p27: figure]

ARBI | Mechanical bench assembly | Revision 9 | 07 Oct 2026 | 16 / 20

Clip holes, diameter 4.5 mm: Y=+/-82. For each main panel i, X=-46+iP+16 and X=-46+(i+1)P-16. P=180.667 mm passive (i=0..2), or 174.4 mm powered (i=0..4).
Anchor holes: X=W/2+50 and W/2+70, Y=-60. W=246.9 / 570.3 mm. Total: 14 / 22 added holes. The older drilling template omits these.

Each clip
M4 x 25 + two washers + locknut to base.
M4 x 16 + washer to plain M4 nut slid in from the side. Use 9 mm OD washers and reviewed removable locking. Inspect supports under the raised stem and nut pocket.

Per passive / powered kit: 12 / 20 shell screws, plain nuts and washers; 14 / 22 base+anchor screws and locknuts; 28 / 44 base washers. Anchor uses two soft loom wraps. Buy separately from original winch fasteners.

Slide captive nuts in before bolting clips down. Deburr and inspect the added holes. Install +Y upward on the post; Z points outward. Fit fixed looms before the panels.

# 16 Fit and remove the shell

Isolate power and secure/de-tension the line. Disconnect/withdraw fixed looms from the closed lower ports before moving the lower fascia or hood.

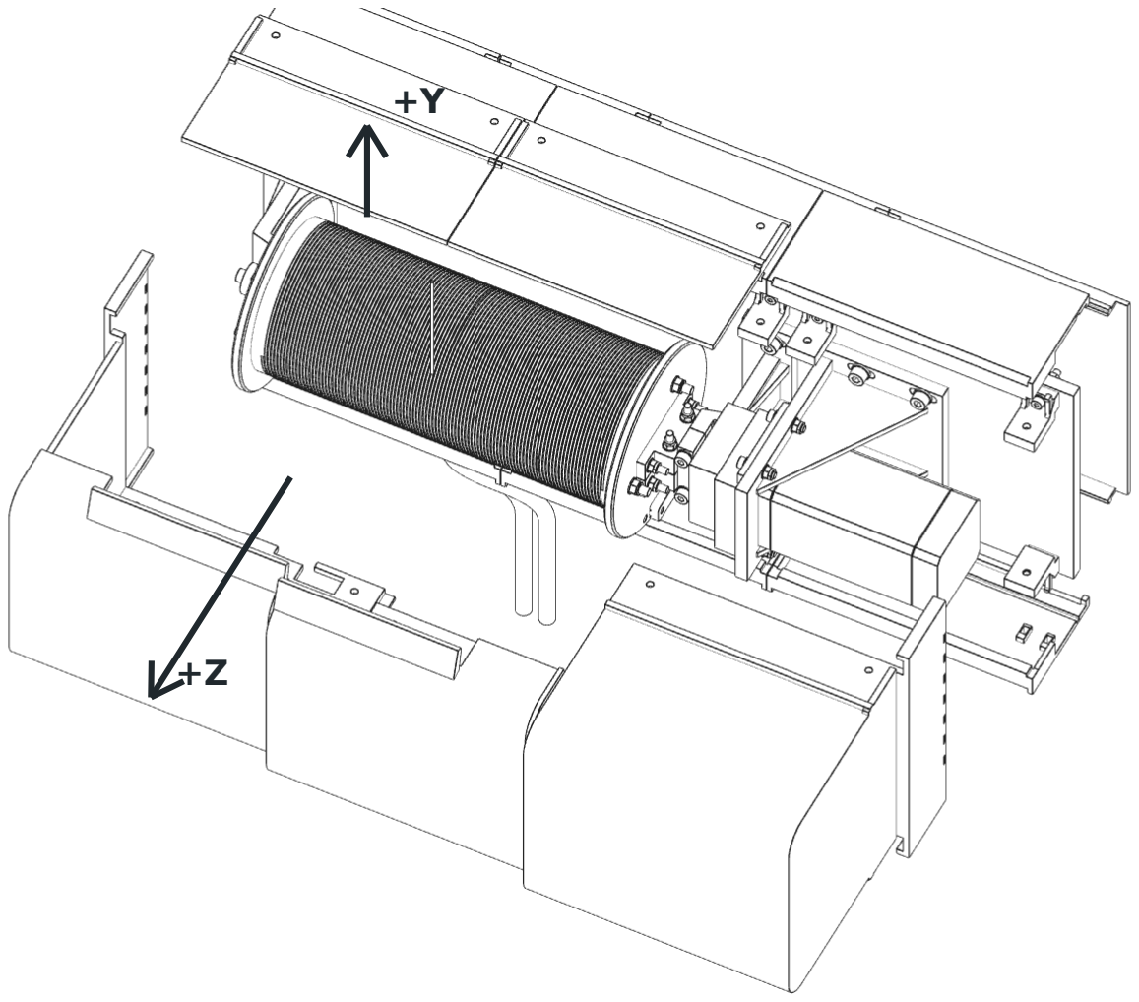
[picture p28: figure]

ARBI | Mechanical bench assembly | Revision 9 | 07 Oct 2026 | 17 / 20

## 1 Fit right to left

Fit the right main panel, then middle panels from right to left, then left. The 7 mm exterior cuffs overlap the next panel. Fit payout shutters and tighten four shell screws per position. Add concealment parts last (page 19).

## 2 Remove shutters first

Remove fascia and rear shields first (page 19), then +Y-side screws. Withdraw each lower shutter toward +Y at least 20 mm; the 24 mm payout slot opens down to the base face. Secure the line inside its corridor.

## 3 Lift left to right

Remove remaining shell screws. Lift main panels outward along +Z, left to right, at least 130 mm. Fixed clips and loom anchor stay on the base. Remove the original coupling guard separately.

# 17 Routing and acceptance

Powered base/shaft remain separate load cases. The full cover is concept-unvalidated: no physical fit, heat, weather or contact-protection acceptance.

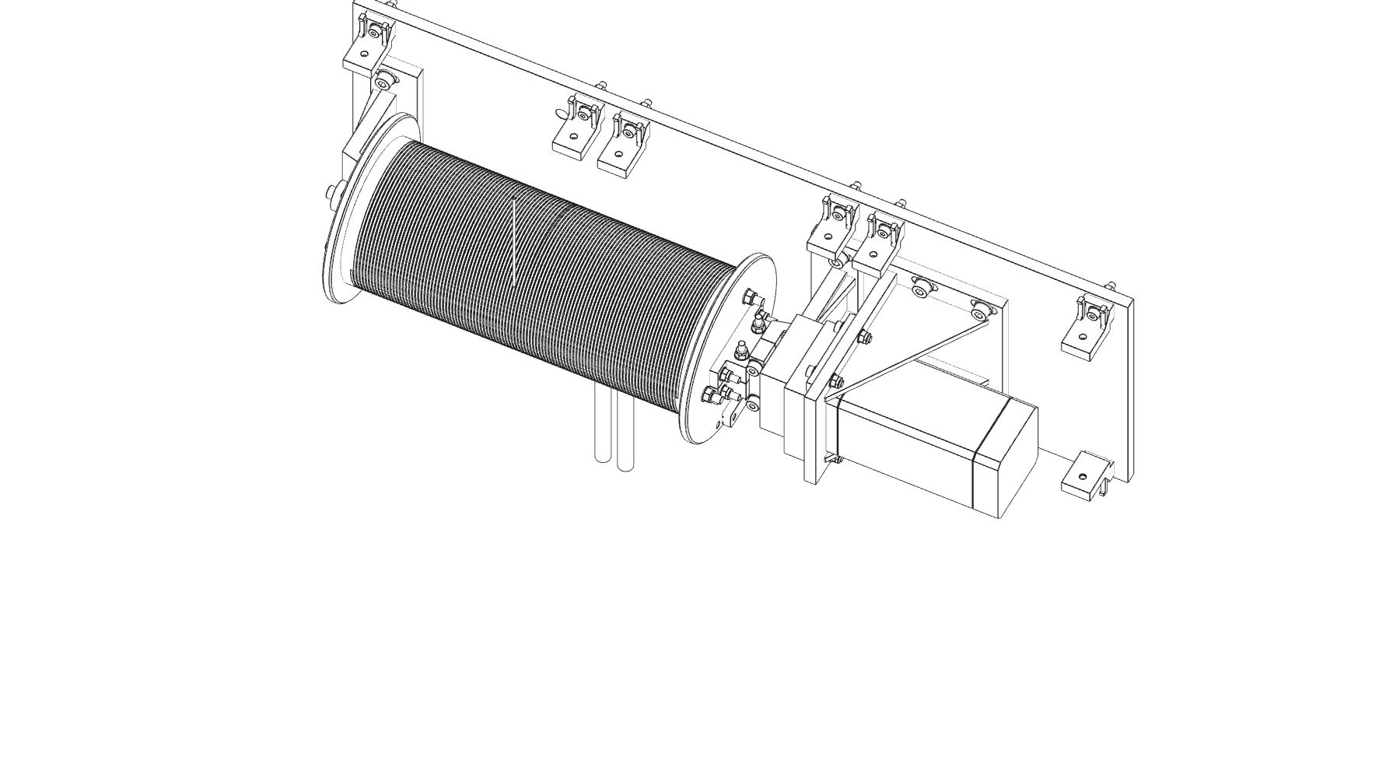
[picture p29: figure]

ARBI | Mechanical bench assembly | Revision 9 | 07 Oct 2026 | 18 / 20

Line: bidirectional payout along +Y across the full winding width. Slot Z=120..144 mm; represented corridor Z=124..140 mm. Nominal line diameters 1.5 / 4.5 mm. Smooth edges, traverse full travel and check fleet angle. The shell is not a fairlead.

Fixed looms: two 14 mm bottom ports beside the pole at X=W/2-55 / W/2-35, Z=13 / 25, for <=10 mm looms. Route below the drum; nominal internal bend 30 mm. Anchor at X=W/2+60, Y=-60. Confirm received bend limits, soft edging and drip/strain relief. Disconnect/withdraw looms before removing the lower pole fascia or hood.

Powered interface still open: a nominal 30 x 18 x 18 mm slip-ring body bay is checked at X=W+54..W+84, Y=-71..-53, Z=71..89. No supplier geometry, bracket or rotating conductor loop is established. Do not power the hybrid line until these are designed and accepted.

Rain and heat: +Y brows and exterior cuffs; baffled seams/end drains; five 10 x 5 mm downward motor vents above the fascia. Inspect rain, condensation, UV, motor temperature and creep at actual duty. PLA is a fit prototype. The near-motor driver is not modeled here; its protected mounting/enclosure still needs electrical design.

Service: with shells off, existing cap/base/motor fasteners retain their access. Release the coupling and caps before lifting the drum/shaft. Repeat alignment, line routing and hand-spin checks on reassembly. Payout openings and skirt gaps can admit fingers/tools; safe guarding remains unverified.

# 18 Concealed fasteners

Bottom-layout replacements: passive left/right and powered right r0.3.0, powered pole middle and one lower pole fascia r0.1.0. Reuse other panels, clips and shutters.

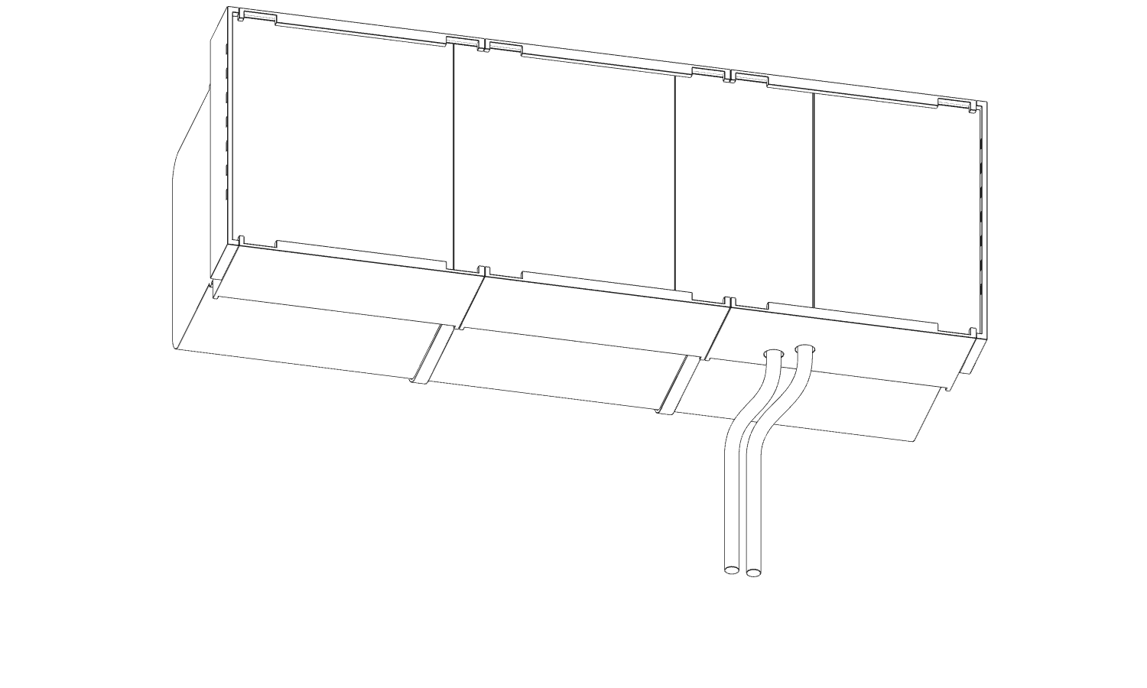
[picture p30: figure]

ARBI | Mechanical bench assembly | Revision 9 | 07 Oct 2026 | 19 / 20

White fascia: 6 strips passive / 10 powered, two per panel position. They cover side screw heads and clip bolts. Rear shields cover base nuts and tips. All actual fasteners remain in the installed illustration.

Rear shields: passive 1 left + 2 right; powered 2 left + 3 right. Add one common blank for an unmounted bench enclosure. Remove that blank before post mounting; add four 25 mm steel M8 standoffs (16 OD / 9 bore). The 102 mm opening clears the nominal 100 mm post. Post/backing-plate hardware on the far side of the timber belongs to the site attachment.

Fit last: tighten and inspect the metal stacks, seat rear shields, lift fascia and shields 2 mm, slide fascia onto the keys, then lower together. Keep drain/vent passages open. Reject keys that bind, crack, creep or release under a straight side pull.

Service first: isolate and secure the line. Lift fascia and rear shields together 2 mm along +Z, using underside finger pockets. Withdraw fascia along +/-Y while lifted; remove rear shields toward -Z. Shell screws then have their original driver access. Remove shutters, then main hoods.

Rear Z=-32 mm; post front at -33 mm. Round-timber saddles and caps: page 20. Structural mounting capacity is unverified. Desk feet use the open service configuration. Key fit, strength, vibration retention and weather behavior are unverified.

# 19 Round timber mount

120 mm nominal timber; regenerate matching saddles for measured diameter. Steel/aluminium capacity, timber fit and bolt bending remain unvalidated.

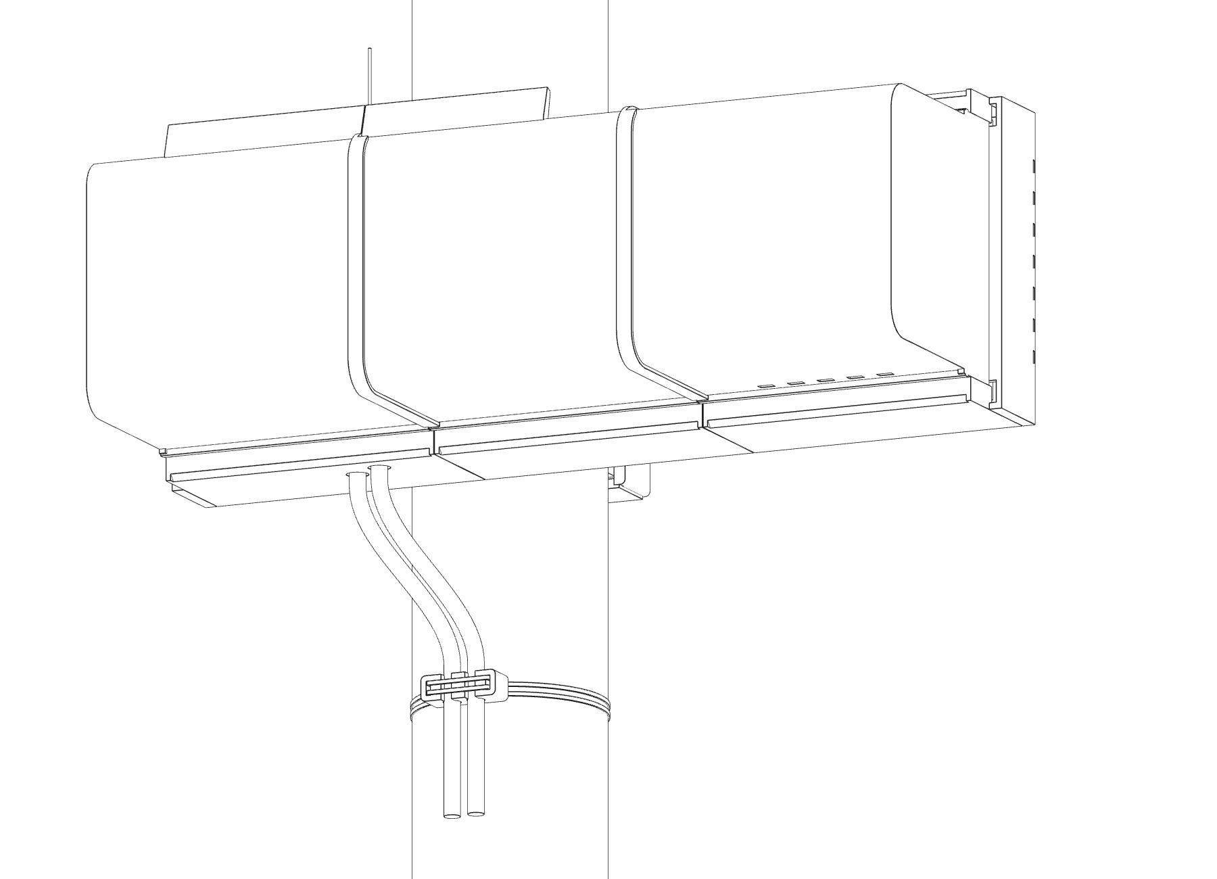
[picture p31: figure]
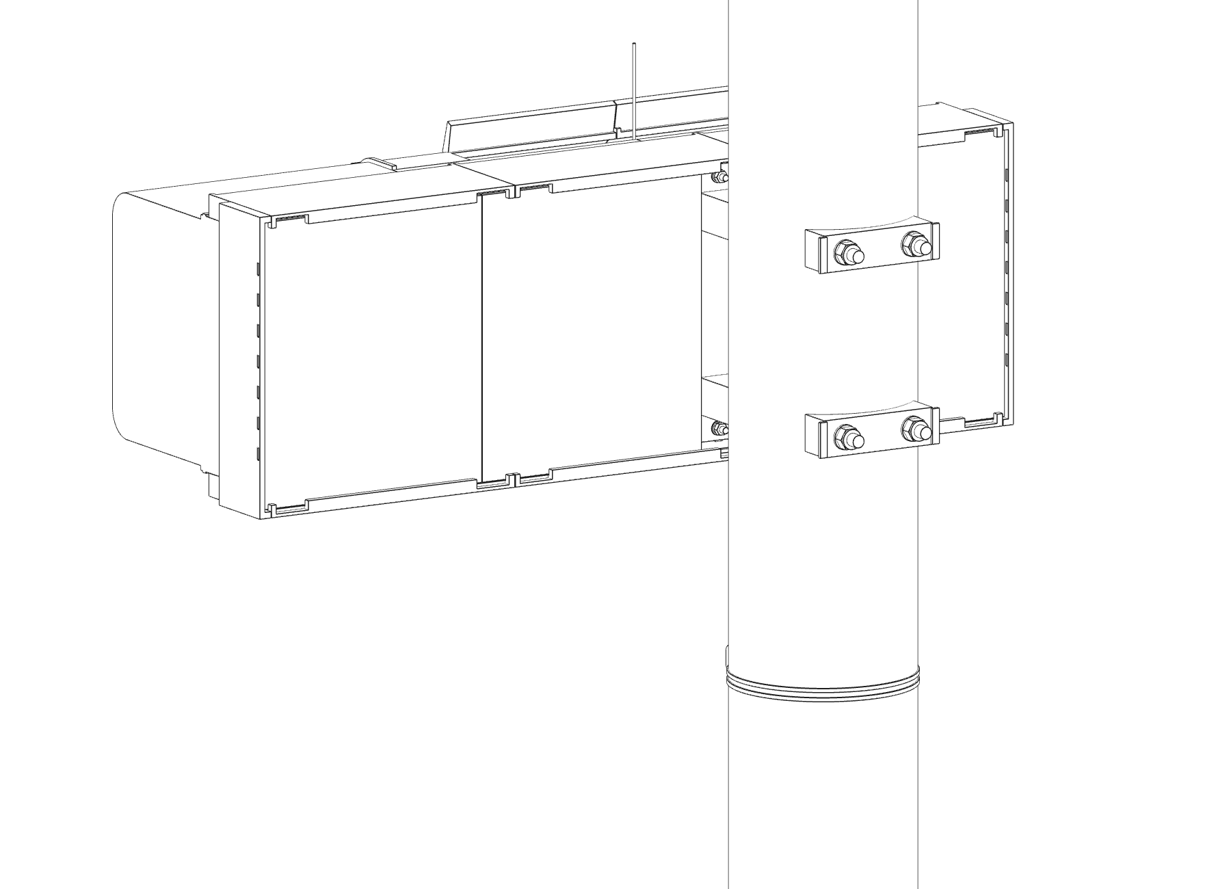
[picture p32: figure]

ARBI | Mechanical bench assembly | Revision 9 | 07 Oct 2026 | 20 / 20
INSTALLED / BOTTOM LOOMS | REAR CAPS REMOVED

Metal load path: 2 front saddles + 2 rear saddles per winch, on the existing 50 x 120 mm M8 pattern. The front centre is 25 mm thick; rear centre 8 mm. Machine these in reviewed metal; do not print them. Keep the bench blank out. This replaces the flat-post spacer/backing stack.

Starting bolts: four M8 x 180 for 120 mm timber; x160 / x200 for 100 / 140 mm. Eight <=24 mm OD washers (1.6 mm thick) and four 8 mm locking nuts. Nominal tip projection 7.8 mm. Confirm contact, received stack and engagement.

Rear nut caps: two white caps and two snug underside closures hide nuts from below. Pull closures down first, then lift caps +Y 40 mm and withdraw. Print fit, closure/gravity-stop retention, vibration and outdoor life need physical tests.

Bottom looms: two stationary <=10 mm cables descend onto the pole through a non-structural two-channel guide and two soft ties. Guide insertion needs compliant print testing. It is not certified strain relief. Release wraps and disconnect/withdraw looms before lower-fascia service.

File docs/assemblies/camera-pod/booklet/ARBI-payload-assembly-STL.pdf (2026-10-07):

ARBI PAYLOAD | MOUNT SET / BENCH EDITION

# Build the payload

Pi 3A+ / Camera Module 3 Standard / two micro servos. Dry bench alternative; deck/yoke r0.1.1, other prints as registered.

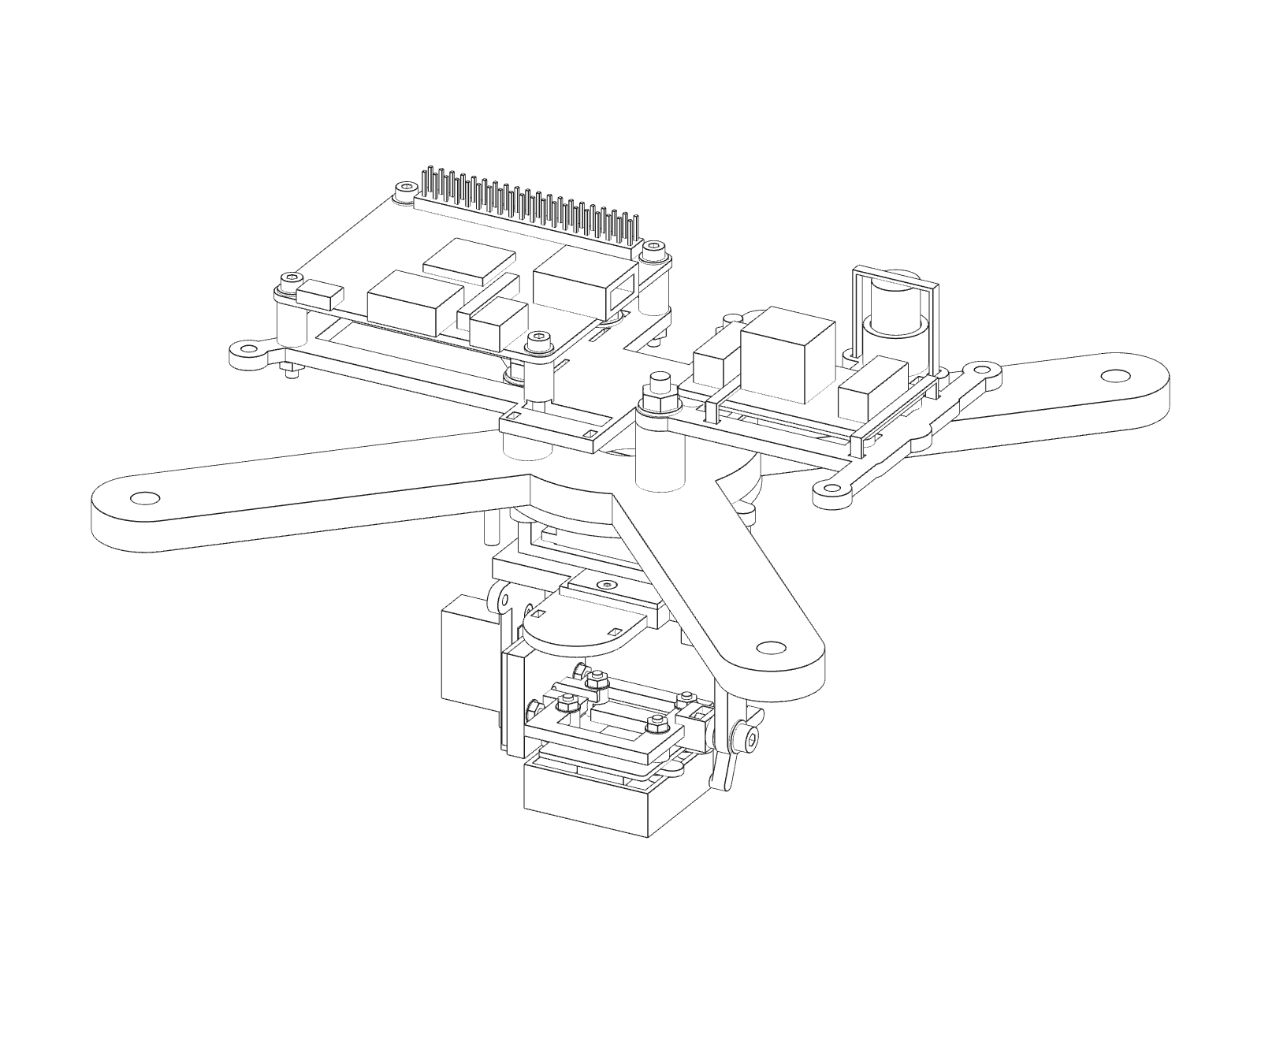
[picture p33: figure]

ARBI | Payload bench assembly | Revision 4 | 07 Oct 2026 | 01 / 14

### THE MISSING PRINTED STRUCTURE IS NOW INCLUDED

A fixed electronics deck, both servo mounts, stock-horn retainers, supported camera cradle, removable pivot support, optical hood and electronics cover. Every illustration uses the supplied STL files.

Fit before the full print
Servo and power-module dimensions remain provisional. Start with the servo coupon and compare the dimension table on page 3 with your received parts. These models are not physically tested.

CAD checks cover rigid geometry, fasteners and motion. Suspended operation still needs mass, strength, balance, cable-flex and electrical checks.

# 01 Printed parts

Print the listed quantity. Line drawings use white faces for clarity; part IDs identify prints. Electronic and metal references are not functional prints.

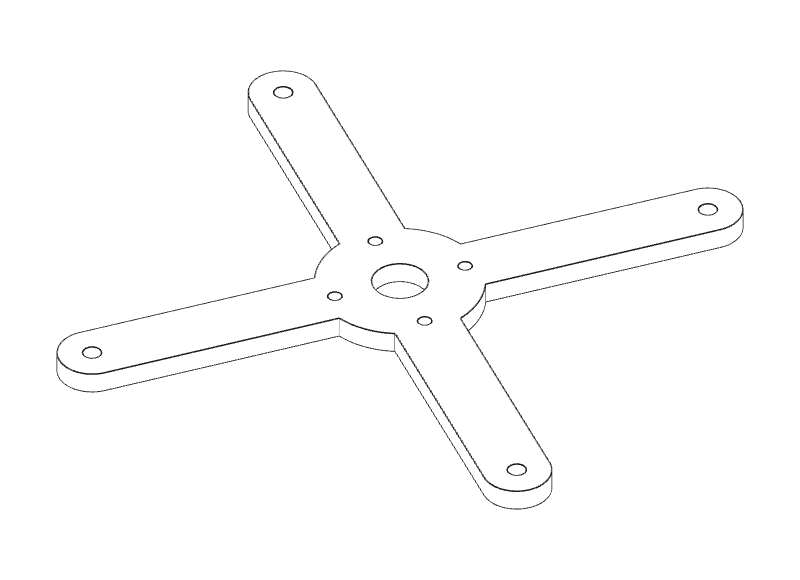
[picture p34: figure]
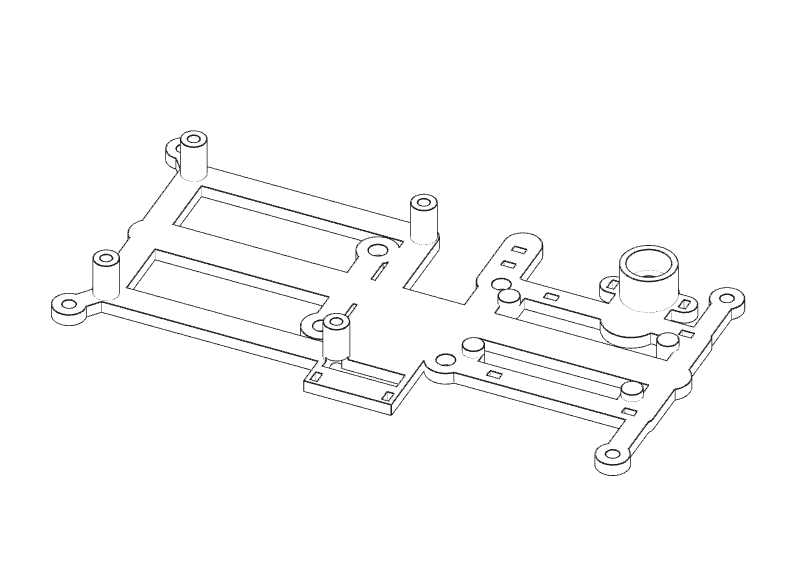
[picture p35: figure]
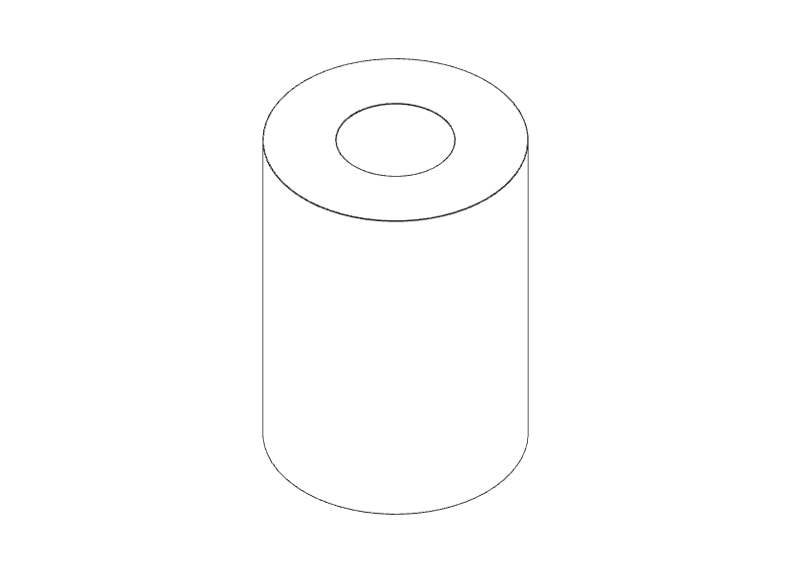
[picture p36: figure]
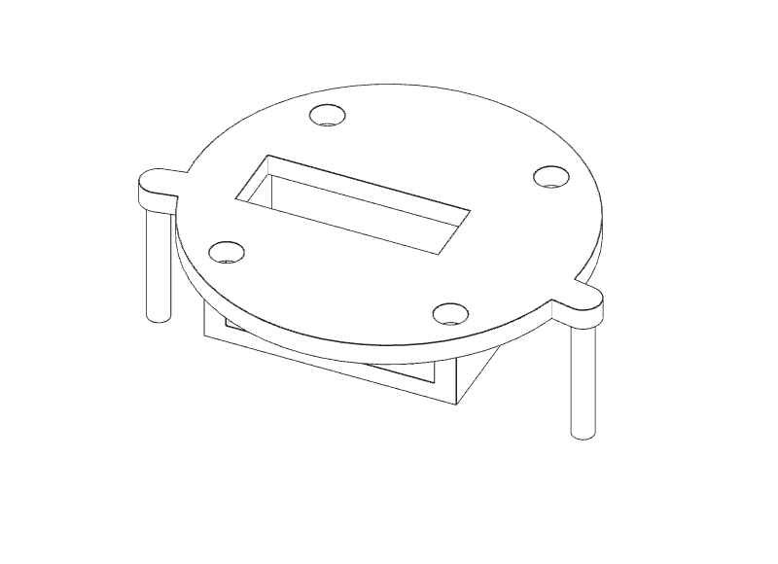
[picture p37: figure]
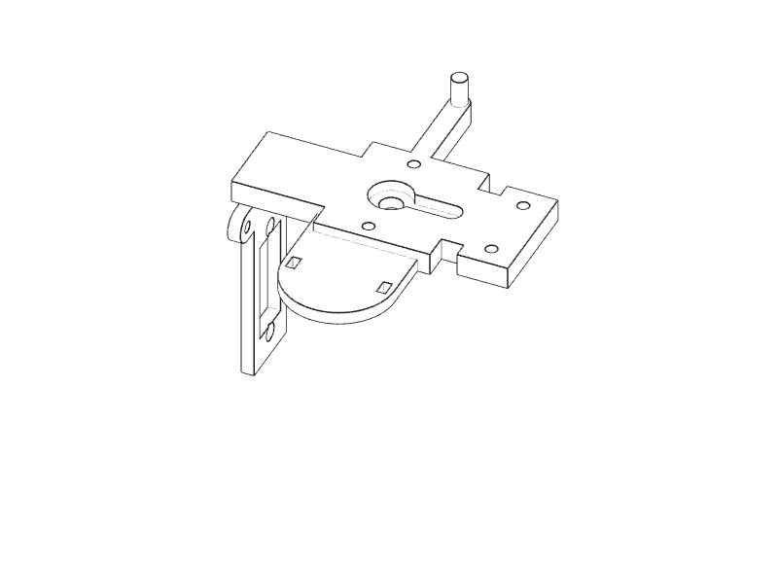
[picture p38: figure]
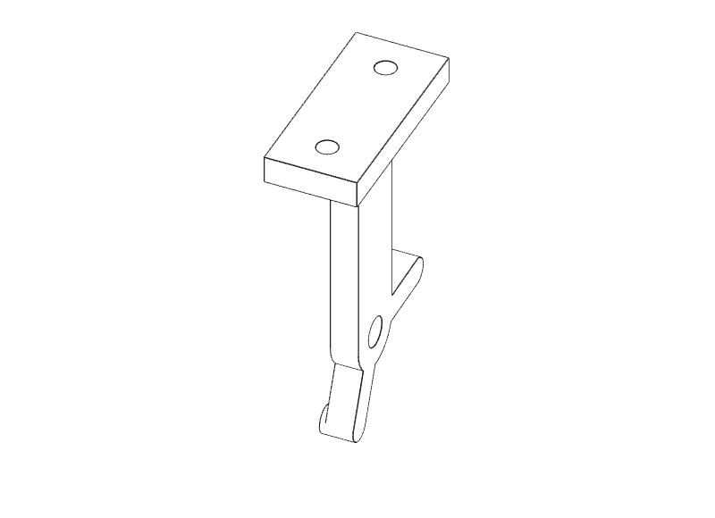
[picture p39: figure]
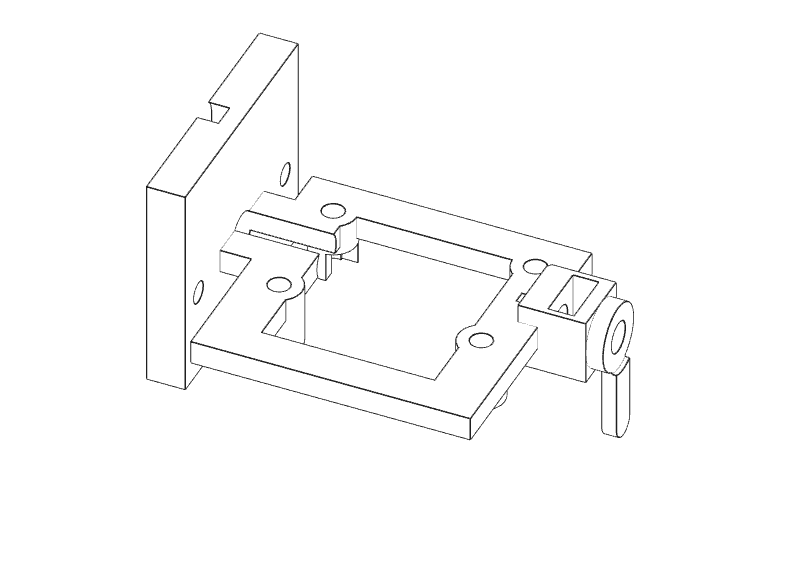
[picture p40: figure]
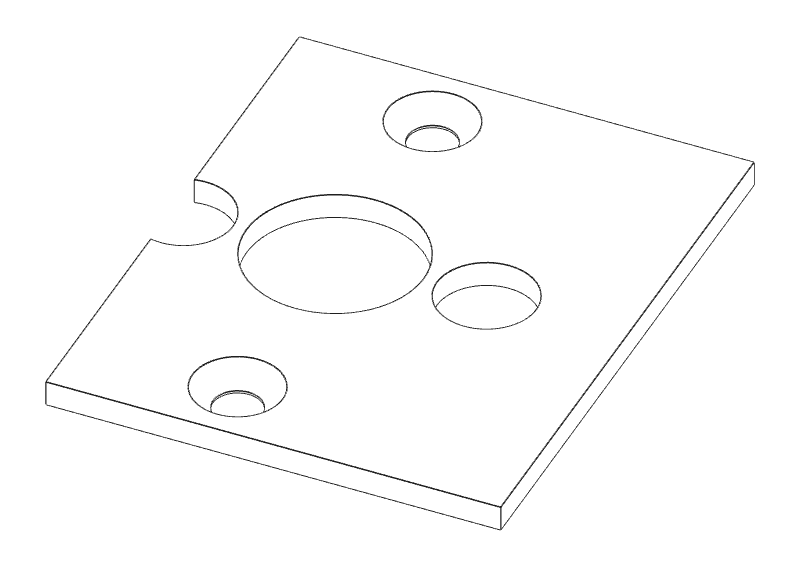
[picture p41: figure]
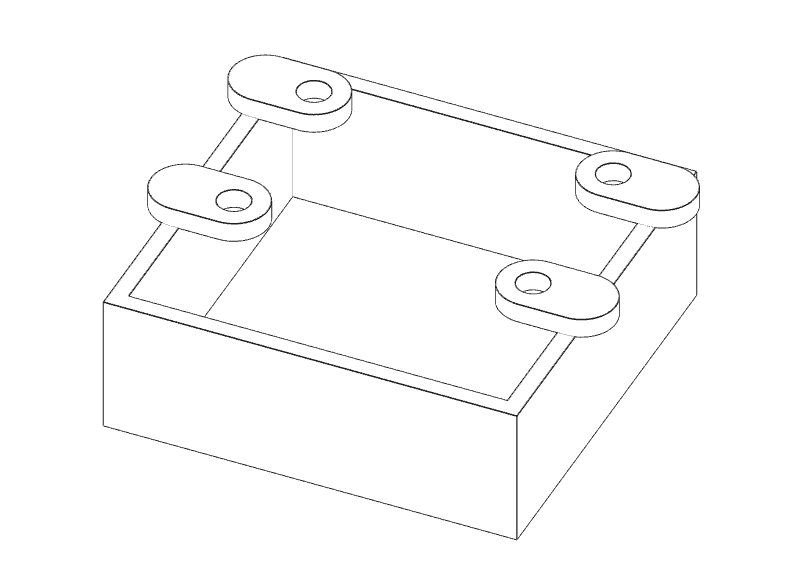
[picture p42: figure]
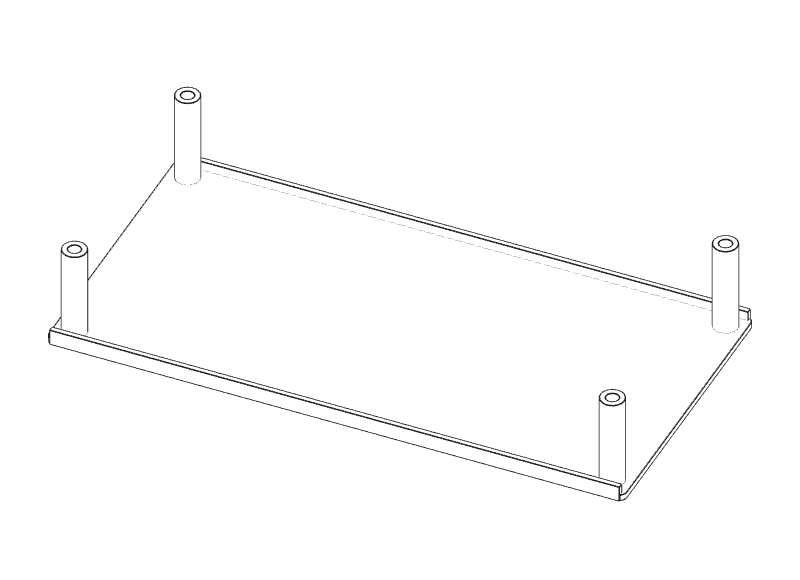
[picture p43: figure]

ARBI | Payload bench assembly | Revision 4 | 07 Oct 2026 | 02 / 14

P01 Existing spider

1 x / r0.1.0

P02 Electronics deck

1 x

P03 Spider spacer

4 x / 14 mm

P04 Pan servo mount

1 x

P05 Pan yoke

1 x

P06 Pivot support

1 x / removable

P07 Camera cradle

1 x

P08 Horn retainer

2 x / identical

P09 Camera hood

1 x

P10 Electronics cover

1 x / removable

T01 Servo fit coupon

1 test print / not installed

PETG starting point:
0.2 mm layers, 3+ walls.
Solid small parts.
Supports on complex brackets.

All STLs are in mm and shifted onto Z=0. Brackets need support planning in the slicer. Remove support scars from mating faces and holes; do not enlarge the horn pocket until it becomes loose.

# 02 Measure before printing

The stock Pi/camera hole patterns are documented. The servo, horn, converter and capacitor must be checked against received hardware.

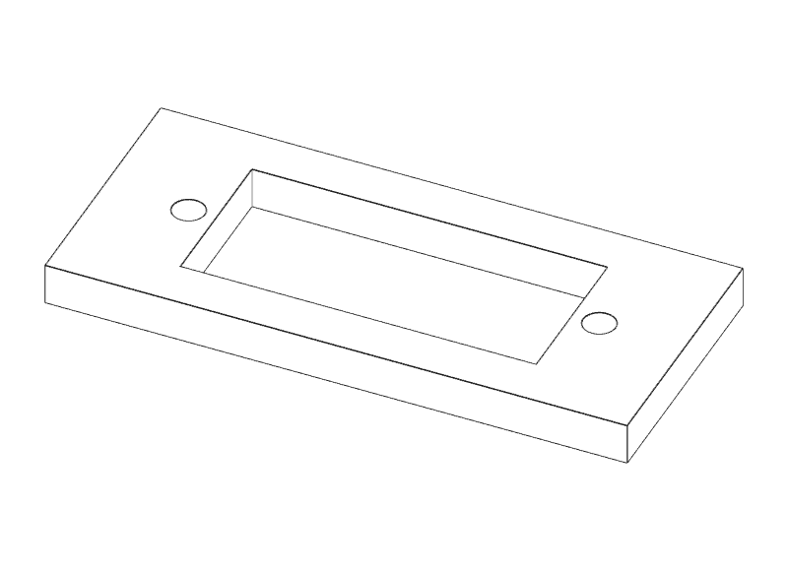
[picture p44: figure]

ARBI | Payload bench assembly | Revision 4 | 07 Oct 2026 | 03 / 14

Test both servos
The body should pass the coupon without force; both lug holes must align. Also measure the shaft offset and height: the coupon cannot check either.
Interface | Nominal model / required check
Servo body | 20 x 8.5 x 18 mm; window 20.8 x 9.3 mm
Servo ears | 27 mm span; 24 mm hole pitch; 1.7 mm holes
Output shaft | 5 mm off body centre; tip 22 mm above case bottom
Stock horn | 8 mm hub; one 12 mm arm; hub 2 mm / arm 1.5 mm thick
Converter / capacitor | 45 x 25 x 15 mm / 10 mm diameter x 16 mm can
Pi / camera holes | 58 x 49 mm, M2.5 / 21 x 12.5 mm, M2

Edit hardware/lib/payload-mounts.scad and the matching reference models if the parts differ, then rebuild and repeat the checks. Use the original servo horns and centre screws; there is no printed spline.

The countersunk servo and horn-retainer screws are intentional. Proud socket heads interfere during rotation. Check the real head diameter and recess seating; no washers go under countersunk heads.

# 03 Install the pan servo

Do this before attaching the mount to the spider. Its large upper opening passes the servo and both mounting ears.

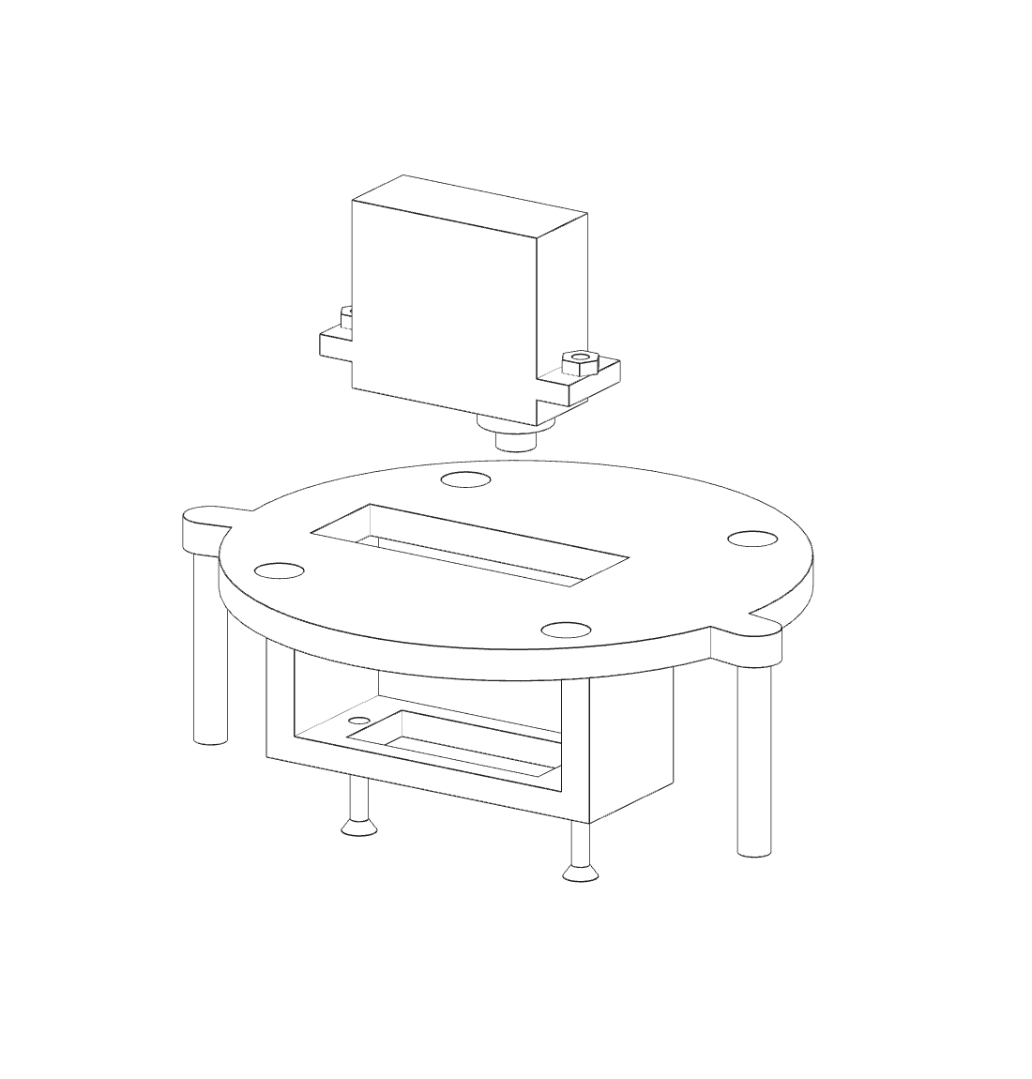
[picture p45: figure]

ARBI | Payload bench assembly | Revision 4 | 07 Oct 2026 | 04 / 14

## 1 Insert from above

Feed the output shaft down through P04. The case passes the body window; the mounting ears rest on the lower lug plate.

## 2 Use recessed ear screws

2 x M1.6 x 6 countersunk screws enter upward from below. Put the two M1.6 nuts above the servo ears. The screw heads must sit flush.

Route the servo lead through an open side with slack at the case exit. Ear holes, nut clearance and centre-screw thread are supplier-dependent; never force an oversized screw into the servo.

# 04 Couple the pan yoke

Set the actual servo neutral with its controller, then disconnect power before fitting the horn. Keep the horn orientation repeatable.


ARBI | Payload bench assembly | Revision 4 | 07 Oct 2026 | 05 / 14

## 1 Capture the supplied horn

Seat the stock horn in the upper pocket of P05. Fit P08 over it: the underside rib bears on the horn arm. Remove free play with a fitted shim if needed.

## 2 Retain and engage

Use 2 x M2 x 10 countersunk screws, two lower washers and two nuts. Push the captured horn onto the pan spline and fit the OEM centre screw through the access hole below.

The rib and pocket match the stated nominal horn only. Do not clamp a different horn by force. At neutral, a short driver reaches the retainer screws from the side below the pan mount; see the access-check limits.

# 05 Install the tilt servo

Leave the opposite pivot support off while engaging the camera horn. P06 is removable so the yoke does not need to be bent apart.


ARBI | Payload bench assembly | Revision 4 | 07 Oct 2026 | 06 / 14

## 1 Insert from the outside

Slide the second servo into the left-side opening of P05. Its output shaft points inward toward the camera; the two ear holes align vertically.

## 2 Recess the two screw heads

Use 2 x M1.6 x 6 countersunk screws from the inner face of the lug plate, with nuts outside the servo ears. Install these before the camera cradle blocks tool access.

At this stage both servos should be retained independently of their horns. The exposed lead exits need relaxed wire loops; the geometric references do not model the actual servo lead or plug.

# 06 Prepare the camera cradle

The camera mounts 5 mm off the tilt-axis centreline. This leaves access to the stock horn screw without crossing a camera mounting hole.


ARBI | Payload bench assembly | Revision 4 | 07 Oct 2026 | 07 / 14

## 1 Fit the tilt horn and retainer

Capture the second stock horn in P07 with P08, 2 x M2 x 8 countersunk screws, two washers behind the carrier and two nuts. Slide the cradle onto the tilt spline while P06 is removed.

## 2 Secure the centre screw first

Fit the OEM centre screw from inside the cradle through its lateral access bore. Fit the camera, hood and four camera bolts after this screw is secure.

Camera stack: M2 x 12 screw + front washer > hood tab > PCB > integral cradle spacer > carrier > rear washer + nut. Use four of each. The rear CSI connector has a clearance recess.

# 07 Close the supported pivot

The M3 pivot provides the opposite-side support. It must rotate freely without squeezing the cradle against the yoke.


ARBI | Payload bench assembly | Revision 4 | 07 Oct 2026 | 08 / 14

## 1 Drop in the pivot nut

Put the M3 plain nut into the open-top pocket in the right cradle boss. Slide P06 onto the yoke from below; its stop pins face the moving cradle tab.

## 2 Fasten the removable support

Use 2 x M2 x 12 screws, four M2 washers and two nuts through the top pad of P05 and flange of P06.

## 3 Fit the pivot screw and shim

Insert M3 x 12 with a 0.5 mm outer washer. Place the 0.7 mm shim in the side gap. Adjust for free travel, then retain the threaded joint without locking the pivot against the support.

# 08 Attach to the spider

Build the mechanical frame before fitting the Pi. This leaves the four upper frame nuts accessible.


ARBI | Payload bench assembly | Revision 4 | 07 Oct 2026 | 09 / 14

## 1 Stack the three levels

P04 pan mount below the existing spider; four P03 spacers above it; P02 electronics deck on top. Align the existing 31.11 mm square mounting pattern.

## 2 Fit four M4 through bolts

Insert M4 x 35 upward from below, with a washer at each end and a plain nut above the deck. Tighten evenly without crushing printed spacers.

The Pi is installed later. Its underside clears the represented frame-screw tips; replacing these bolts with longer ones requires another check.

# 09 Mount compute and power

All heavy electronics stay on the fixed deck. Disconnect power while mounting boards and connecting the camera ribbon.


ARBI | Payload bench assembly | Revision 4 | 07 Oct 2026 | 10 / 14

## 1 Mount the Pi on four posts

Use 4 x M2.5 x 20 screws, eight M2.5 washers and four nuts. Insert the microSD card and connect the CSI cable while the cover is off.

## 2 Retain the converter

Seat the board on its four pads. Two 2.5 mm insulated ties pass through the deck slots and over clear PCB strips. Confirm the real module has no components or terminals under those strips.

## 3 Fit the capacitor

Put an insulating sleeve on the leads, seat the can in its loose cup, and loop a tie over the can through the two side slots. Keep polarity visible and leads separated.

Validate regulated 5 V and polarity before connecting electronics. Servo supply comes from the regulated rail; GPIO provides signals, not motor power.

# 10 Route cables; add the cover

The 60 mm flat CSI mesh is only a reference segment. It is not the cable length needed by this assembled mechanism.


ARBI | Payload bench assembly | Revision 4 | 07 Oct 2026 | 11 / 14

Provide two relaxed ribbon loops
Use the broad tie pads on the deck and pan yoke with a soft protective wrap. Route the fixed-to-pan loop through an open gap between spider arms and outside the servo sweep. Leave a separate pan-to-camera loop for tilt. Keep the CSI connector accessible.

Hand-check all four pan/tilt corner poses with the actual ribbon before choosing its length. Stop before any tension, twist concentration, sharp crease or rubbing. The CAD check does not simulate cable flex.

Fit P10 last: 4 x M3 x 35, eight M3 washers and four nuts. The cover lifts straight off after its bolts are removed. It is a splash shield; the exposed gimbal and electronics are not waterproof.

# 11 Hardware for one assembly

Counts below follow the illustrated assembly. Plain nuts are used in the checked envelopes. Confirm actual screw heads and supplied servo hardware.

ARBI | Payload bench assembly | Revision 4 | 07 Oct 2026 | 12 / 14
Location | Screws | Nuts / washers
Spider / deck | 4 x M4 x 35 | 4 M4 nuts; 8 M4 washers
Pi | 4 x M2.5 x 20 | 4 M2.5 nuts; 8 M2.5 washers
Servo ears | 4 x M1.6 x 6 COUNTERSUNK | 4 M1.6 nuts; no head washers
Pan horn retainer | 2 x M2 x 10 COUNTERSUNK | 2 M2 nuts; 2 lower washers
Tilt horn retainer | 2 x M2 x 8 COUNTERSUNK | 2 M2 nuts; 2 rear washers
Camera / hood | 4 x M2 x 12 | 4 M2 nuts; 8 M2 washers
Pivot support | 2 x M2 x 12 | 2 M2 nuts; 4 M2 washers
Tilt pivot | 1 x M3 x 12 | 1 M3 nut; 0.5 mm washer + 0.7 mm shim
Electronics cover | 4 x M3 x 35 | 4 M3 nuts; 8 M3 washers
Servo centres | 2 x original horn screws | Thread and length depend on servo

Also: two converter ties, one capacitor tie, and ties/soft sleeves for the incoming wire and CSI anchor pads. Do not use a cable tie as the independent tensile termination of a positioning line.

# 12 What the CAD check proves

ARBI | Payload bench assembly | Revision 4 | 07 Oct 2026; PAN -90 / TILT 70; PAN 0 / TILT 0; PAN +90 / TILT 70; Check; Result / limit; Rigid travel grid; 555 poses; 5-degree steps; no intersections above 0.005 mm3; Mechanical stops; Contact beyond +/-95 pan and -5 / +75 tilt; usable targets +/-90 and 0..70; Assembly and service; Insertion, cover-removal and short-driver paths checked in the supplied; report; Optical opening; Nominal camera viewing volume checked against represented solids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

Checked against the declared nominal hardware. Real parts, print shrinkage, bolt tolerances and cable behaviour still
need inspection.

The original 170 g flying ceiling is not demonstrated by this bench design. Slicer infill changes mass; weigh the
complete build. A lighter chassis/cover and a new mass check are needed before suspended use.

# 13 Final bench inspection

Support the spider on a fixture so the camera hangs free. Do not rest the payload on its optical hood or force a geared servo by hand.

ARBI | Payload bench assembly | Revision 4 | 07 Oct 2026 | 14 / 14

## 1 Inspect the retained parts

No loose PCB, horn, pivot nut or strap. Countersunk heads fully seated. Camera centre screws installed. The pivot remains free and has no excessive side play.

## 2 Check cables before powered motion

Verify both slack loops and all four travel corners with the drive disengaged where practical. Calibrate narrow software limits first, then increase only after observing clearance.

## 3 Check power and imaging

Verify the converter output before attaching the Pi. Check for brownouts during servo motion, focus and capture. Keep hands, loose wires and tools away from the moving brackets.

## 4 Record what was built

Measure servo/converter dimensions, revisions, print settings, complete mass, movement limits and faults. No load, fatigue, weather or suspended-operation test has been performed here.

Pack contents
41 checked STLs, assembled GLB, current source snapshot, assembly/figure transforms, source hashes and JSON check reports. Only models/printable contains fabrication parts; the fit coupon is not installed.

Sources and open interfaces
Full source URLs and assumptions: sources.json. Line terminations, docking-stud interface, actual ribbon behaviour, electrical performance and flying mass remain open; they are not supplied as verified interfaces.

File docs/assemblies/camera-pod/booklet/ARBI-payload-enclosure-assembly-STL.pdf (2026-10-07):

ARBI PAYLOAD | RAIN / SPLASH EDITION

# Build the rain enclosure

Rounded white roof and black lower chassis; Camera Module 3 Standard, Pi 3A+ and two micro servos. Ordinary-rain/splash concept.


ARBI | Payload rain enclosure | Revision 2 | 07 Oct 2026 | 01 / 16

### CURRENT CAD, COMPLETE ASSEMBLY

Every illustration uses the checked STL meshes. The continuous roof, lower tray, removable fairing, servo boot and rear camera cowl supplement the existing gimbal and optical hood.

Measure the received servo, horn, converter and connectors first. These are nominal references, with no physical fit or rain test and no claimed ingress rating.

Build unpowered on a supported bench fixture. Complete mass, cable movement, heat, electrical performance and suspended operation require separate checks.

# 01 Chassis and gimbal prints

Print quantities below. White-face line drawings show every part; IDs identify prints. Boards and metal are nominal references.


ARBI | Payload rain enclosure | Revision 2 | 07 Oct 2026 | 02 / 16

P01 Spider

1 x / 0.1.0

P02 Electronics deck

1 x / 0.1.1

P03 14 mm spacer

4 x / 0.1.0

P04 Pan mount

1 x / 0.1.0

P05 Pan yoke

1 x / 0.1.1

P06 Pivot support

1 x / 0.1.0

P07 Camera cradle

1 x / 0.1.0

P08 Horn retainer

2 x / 0.1.0

P09 Optical hood

1 x / 0.1.0

T01 Fit coupon

1 x / 0.1.0

Reprint P02 deck and P05 yoke at r0.1.1: the deck has the CSI passage; the yoke has boot attachment ears. The coupon is a test print and is not installed.

STLs use mm and Z=0 print-bed placement. PETG is a starting material; plan supports in the slicer, inspect mating faces and holes, and weigh the sliced and printed parts.

# 02 Enclosure prints

P10 replaces the bench electronics cover. P11-P14 are new parts. Use white for the roof and camera cowl; black for the tray, fairing and servo boot.


ARBI | Payload rain enclosure | Revision 2 | 07 Oct 2026 | 03 / 16

P10 White rain hood

Closed roof; inside-loaded M3 nut pockets

P11 Black rain tray

Perimeter skirt, raised lip and downward outlets

P12 Tilt servo boot

Moving cover; servo retained separately

P13 White camera cowl

Four second camera nuts retain the cowl

P14 Black pan fairing

Removes downward; four posts pass between spider arms

These covers manage ordinary rain and splash; openings and moving interfaces are present. Print orientation, drain performance, seals, heat and outdoor exposure remain unverified.

# 03 Measure actual hardware

The Pi/camera mounting patterns follow cited drawings. Servo, horn, converter, capacitor and connectors remain provisional.


ARBI | Payload rain enclosure | Revision 2 | 07 Oct 2026 | 04 / 16

Test both servos
Check case fit and both lug holes, then measure shaft offset, output height, supplied horn and the lead exit. The coupon tests only the first two.
Interface | Nominal envelope / required check
Servo | 20 x 8.5 x 18 mm; 27 mm ears, 24 mm hole pitch, 1.7 mm holes
Output / horn | 5 mm shaft offset; tip 22 mm above case; 8 mm horn hub, one 12 mm arm
Converter / capacitor | 45 x 25 x 15 mm / 10 mm can diameter, 16 mm height
Pi / camera | 58 x 49 mm M2.5 pattern / 21 x 12.5 mm M2 pattern
Incoming lead | 6 mm diameter through 8 mm base outlet; fit an actual soft sleeve or grommet
CSI / servo outlets | 16 x 0.3 mm ribbon; 4 x 2 mm fixed servo lead reference

Connector plugs stay inside the enclosure. Fit leads before closing the tray/roof. Do not assume a plug fits through a bare-wire outlet or use a tie as a positioning-line tensile termination.

# 04 Install the pan servo

Fit the servo before attaching its mount to the spider. The upper opening passes the case and ears.


ARBI | Payload rain enclosure | Revision 2 | 07 Oct 2026 | 05 / 16

## 1 Feed the shaft downward

Insert the servo through P04 from above. The ears rest on the lower lug plate; the shaft points toward the pan horn.

## 2 Seat the recessed screws

Use 2 x M1.6 x 6 countersunk screws upward from below and two M1.6 nuts above the ears. No head washers.

Countersunk servo and horn-retainer heads are essential. Proud heads collide during rotation. Compare real head diameter, recess seating and supplied hardware with the checked reference.

# 05 Couple the pan yoke

Set servo neutral electrically, disconnect power, then fit the original horn. There is no printed spline.


ARBI | Payload rain enclosure | Revision 2 | 07 Oct 2026 | 06 / 16

## 1 Capture the stock horn

Place the horn in the upper pocket of P05. P08 bears on its arm. Shim a loose horn only after checking its actual shape.

## 2 Fasten and engage

2 x M2 x 10 countersunk screws, two lower washers and two nuts retain P08. Engage the spline and install the original centre screw from below.

The original centre screw thread and length are supplier dependent. Local 15 mm straight-tip tool access is checked; driver handles and every possible approach are not represented.

# 06 Tilt servo and moving boot

Leave the opposite pivot support off. The boot is fitted after retaining the servo and routes its lead through the lower opening.


ARBI | Payload rain enclosure | Revision 2 | 07 Oct 2026 | 07 / 16

## 1 Slide the servo inward

Insert from the left into P05. The shaft faces the camera. Use 2 x M1.6 x 6 countersunk ear screws from the inner lug face and two nuts outside.

## 2 Fit the removable boot

Place P12 around the retained servo. Use 2 x M2 x 8 screws from the outside, two M2 washers and two nuts at the yoke ears. Keep the case lead loose.

After its two bolts are removed, P12 withdraws 20 mm outward, lowers 15 mm, then withdraws another 20 mm. It does not retain the servo, seal the spline, or establish the actual lead-exit position.

# 07 Camera cradle and rear cowl

Secure the tilt horn centre screw before fitting the camera. P13 sits behind the board; P09 remains at the optical face.


ARBI | Payload rain enclosure | Revision 2 | 07 Oct 2026 | 08 / 16

## 1 Capture and engage the tilt horn

Use P08, 2 x M2 x 8 countersunk screws, two rear washers and two nuts. Engage the spline with P06 removed, then install the original centre screw.

## 2 Retain camera, then cowl

Use 4 x M2 x 18 through the front washers, P09, PCB and cradle. Rear washers and first nuts secure the camera. Fit P13 over the rear, then add four second M2 nuts.

The first camera nuts remain at the cradle; the second nuts secure only P13. Route the camera CSI connector through the rear relief. Remove rear nuts, lift P13 by 14 mm, then withdraw it 45 mm toward -Y.

# 08 Close the supported pivot

Fit the opposite support after spline engagement. The pivot must rotate freely without squeezing the cradle.


ARBI | Payload rain enclosure | Revision 2 | 07 Oct 2026 | 09 / 16

## 1 Drop in the M3 pivot nut

Insert the plain M3 nut through the open-top cradle pocket. Fit P06 from below; its stop pins face the cradle tab.

## 2 Fasten the removable support

Use 2 x M2 x 12 screws, four M2 washers and two nuts at the yoke top pad.

## 3 Fit the pivot and shim

Use M3 x 12 with a 0.5 mm outer washer and 0.7 mm gap shim. Adjust for free motion and retain the joint without locking the pivot.

# 09 Lower base and frame

Fit P11 before the electronics deck and gimbal obstruct access. The spider remains the canonical structural part.


ARBI | Payload rain enclosure | Revision 2 | 07 Oct 2026 | 10 / 16

## 1 Place the upper tray

Lower P11 onto the spider before spacers or electronics are fitted. Keep its raised lip upward and outlets downward.

## 2 Fit the fairing from below

P14 posts pass between the four arms. Use 4 x M2 x 25 upward through the lower washers; four M2 nuts sit above the tray floor.

## 3 Stack the frame levels

P04 below the spider; four P03 spacers through the tray; P02 on top. Fit 4 x M4 x 35 upward, eight washers and four nuts.

Fit the fairing nuts before the deck blocks access. For service, secure pan at 45 degrees and tilt at 0, isolate power, and disconnect or feed harness slack before lowering. P12 may remain fitted.

# 10 Mount compute and power

Fixed electronics stay on P02. Work with power disconnected; route the leads before fitting the roof.


ARBI | Payload rain enclosure | Revision 2 | 07 Oct 2026 | 11 / 16

## 1 Mount the Pi on four posts

Use 4 x M2.5 x 20 screws, eight washers and four nuts. Fit the microSD and CSI cable while the roof is off.

## 2 Tie the converter to its pads

Two 2.5 mm insulated ties pass through deck slots over clear PCB strips. Confirm there are no actual components beneath these strips.

## 3 Retain the capacitor

Insulate its leads, seat it in the loose cup and use the separate tie. Preserve polarity and separation.

Verify regulated 5 V and polarity before connecting the Pi. GPIO carries servo signals; the regulated supply powers the motors.

# 11 Route the downward outlets

Tray underside at left; tray and fairing omitted at right to expose the nominal power route. Actual connectors, cable bends and weather seals require fitting.


ARBI | Payload rain enclosure | Revision 2 | 07 Oct 2026 | 12 / 16
Outlet axis | Reference and route
Power X=-8, Y=31 | 6 mm nominal lead: descend to Z=-14, across to X16/Y37, down to Z=-42, then out to Y60
CSI X=0, Y=-27 | 16 x 0.3 mm ribbon; centre it at Y=-28 within the slot, then bend away from the spider hub before descending
Servo X=-22, Y=-32 | 4 x 2 mm lead reference; bend away from spider arm before descending
Moving covers | Boot lower exit and cowl rear CSI relief; leave a separate pan-to-camera loop

The shown lead is a rigid power-route proxy, checked at 111 poses. Use soft sleeves, ties and a drip loop; actual bend radius and flexible CSI/servo loops still require bench inspection.

# 12 Close the continuous roof

The roof has no fastener penetrations. Four plain M3 nuts load sideways into blind columns; bolts enter from underneath.


ARBI | Payload rain enclosure | Revision 2 | 07 Oct 2026 | 13 / 16

## 1 Preload four captive nuts

Slide one plain M3 nut into each inward-facing window. Inspect pocket seating before lowering P10 over the tray lip. Keep wires away from the lip and columns.

## 2 Fasten from below

Use 4 x M3 x 35 with four lower M3 washers. The bolts pass through base and deck into the captive nuts. No roof washers are fitted.

For service, remove the four lower bolts and lift the roof vertically with its captured nuts. Confirm drain slots stay open; test seals, drip paths and internal temperatures before outdoor use.

# 13 Hardware for one assembly

Counts follow the actual assembly definition. Plain nuts and nominal heads are checked; supplied servo-centre hardware remains provisional.

ARBI | Payload rain enclosure | Revision 2 | 07 Oct 2026 | 14 / 16
Location | Screws | Nuts / washers
Spider / deck | 4 x M4 x 35 | 4 nuts; 8 washers
Pi | 4 x M2.5 x 20 | 4 nuts; 8 washers
Servo ears | 4 x M1.6 x 6 countersunk | 4 nuts; no head washers
Pan retainer | 2 x M2 x 10 countersunk | 2 nuts; 2 washers
Tilt retainer | 2 x M2 x 8 countersunk | 2 nuts; 2 washers
Camera / optical hood / cowl | 4 x M2 x 18 | 8 nuts; 8 washers
Tilt boot | 2 x M2 x 8 | 2 nuts; 2 washers
Pivot support | 2 x M2 x 12 | 2 nuts; 4 washers
Tilt pivot | 1 x M3 x 12 | 1 nut; 0.5 washer + 0.7 shim
Rain hood / tray | 4 x M3 x 35 | 4 captive nuts; 4 lower washers
Pan fairing | 4 x M2 x 25 | 4 nuts; 4 lower washers
Servo centres | 2 x original horn screws | Verify actual thread / length

Also: two converter ties, one capacitor tie, and soft sleeves/ties for lead anchoring. The pack includes simplified hardware references to show the complete retained assembly.

# 14 CAD evidence and limits

Geometry checks use final exported meshes and the same assembly transforms as these figures. Physical fit, load and rain performance remain unverified.


ARBI | Payload rain enclosure | Revision 2 | 07 Oct 2026 | 15 / 16
PAN -90 / TILT 70 | PAN 0 / TILT 0 | PAN +90 / TILT 70
Check | Result / scope
Rigid motion grid | 555 poses; 5-degree steps; no intersections above 0.005 mm3
Mechanical stops | Contact outside usable +/-90 pan, 0..70 tilt
Assembly and service | 20 sampled paths; short local driver/socket envelopes
Cable outlets | 5 nominal opening envelopes; no flexible-cable simulation
Fixed power route | 111 rigid-route poses; incorrect straight route detects the pan stop
Optical opening | 66 x 41 degree Standard-camera viewing volume to 80 mm
Full-solid PETG mass | 248.3 g before electronics, wires and metal hardware

The 170 g flying ceiling is not demonstrated. Slicer settings change mass; weigh the completed build. Sampled rigid checks do not prove continuous clearance, temperature, sealing, strength or safe flight.

# 15 Final supported bench check

Support the spider with the camera free. Do not rest the assembly on the camera hood or force geared servos by hand.

ARBI | Payload rain enclosure | Revision 2 | 07 Oct 2026 | 16 / 16

## 1 Inspect fastening

Confirm seated countersunk heads, retained horns, both camera nut sets, boot bolts and captive M3 nuts. The pivot must remain free.

## 2 Inspect wires and ports

Fit protective sleeves, strain relief and drip loops. No plug is trapped; ribbon loops clear all four travel corners without sharp bends or tension.

## 3 Measure power, heat and imaging

Check converter voltage/polarity before the Pi. Test servo motion, brownouts, focus and framing, then record internal temperatures with the roof closed.

## 4 Record the physical build

Record received dimensions, source revision, print settings, sliced/actual mass, usable limits, faults and a controlled rain/splash test. No IP rating or suspended-use approval is supplied.

Pack contents
48 checked STLs, assembled GLB, canonical CAD snapshot, model/figure transforms, source hashes, configuration and JSON geometry/service reports.

Source and open interfaces
See sources.json for nominal hardware. Actual seals, ribbon motion, electrical performance, flying mass, line tensile terminations and docking remain open.

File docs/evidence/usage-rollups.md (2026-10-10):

# Usage ingestion and billing-period host evidence

- Date: 2026-10-11
- Work record: [#35](https://github.com/gredice/arbi/issues/35)
- Tested implementation: source and fixtures in this PR; merge commit identifies the revision
- Setup: isolated Linux x86-64 executor; Node 24.19.0, repository-pinned pnpm 11.5.2;
  PGlite 0.5.8 and a temporary socket-only PostgreSQL 18.4 cluster
- Inputs: synthetic identity, Ed25519 keys, counters and plans; no live SIM, provider,
  deployment configuration, private media or production credentials
- Reviewer: automated assertions and PR review; no qualified physical reviewer

## Covered cases

The [usage suite](../../apps/arbi-dashboard/src/usage/test-support.ts) verifies identical
retry, changed sequence/content, intersecting windows, reset epochs, atomic conflicting
batches, late reporting, UTC days, counters above JavaScript's safe-integer range,
unavailable versus zero, layer/partition separation, residual attribution and shared
viewer metadata. Zagreb DST/month boundaries split 101 bytes into estimated 50/51-byte
slices while retaining the original measured window. Rollover distinguishes known
capped carry from unknown carry.

Native tests additionally cover wrong-site/current-authority/proof/origin failures,
audited append-only invalidation, idempotent correction retry, authenticated replacement,
two concurrent duplicate admissions through independent pools, overlapping-admission
conflict and an injected SQL failure proving correction and audit roll back together.
Reports exclude credentials and fail on unsupported query/rate limits.

PGlite does not provide fsync; it skips the two durable authorization/correction cases.
The native suite executes those cases with PostgreSQL durability checks enabled.
CI runs the ordinary and native suite through the dashboard's existing runner.

Local results: dashboard lint/typecheck and build passed; the ordinary dashboard
suite passed 59 tests with 10 explicitly skipped native/durability cases. The native
PostgreSQL suite passed all 28 tests with no skips, including every usage audit case.
Built HTTP checks passed for ordinary starts and branch previews. Documentation links
and whitespace checks passed. The native runtime was supplied in a temporary directory
because the executor had no system PostgreSQL installation; no runtime binary is committed.

## Remaining evidence

Actual interface coverage, carrier rounding/billing, live Gredice/Neon/Vercel integration,
configured history retention/backups, selected-host power-loss durability and installed
operation remain unverified. The bounded query requires a narrower interval if more than
4,096 source windows match; it reports capacity rather than a partial total. No result
certifies carrier invoice parity or clears any local motion/update safety gate.

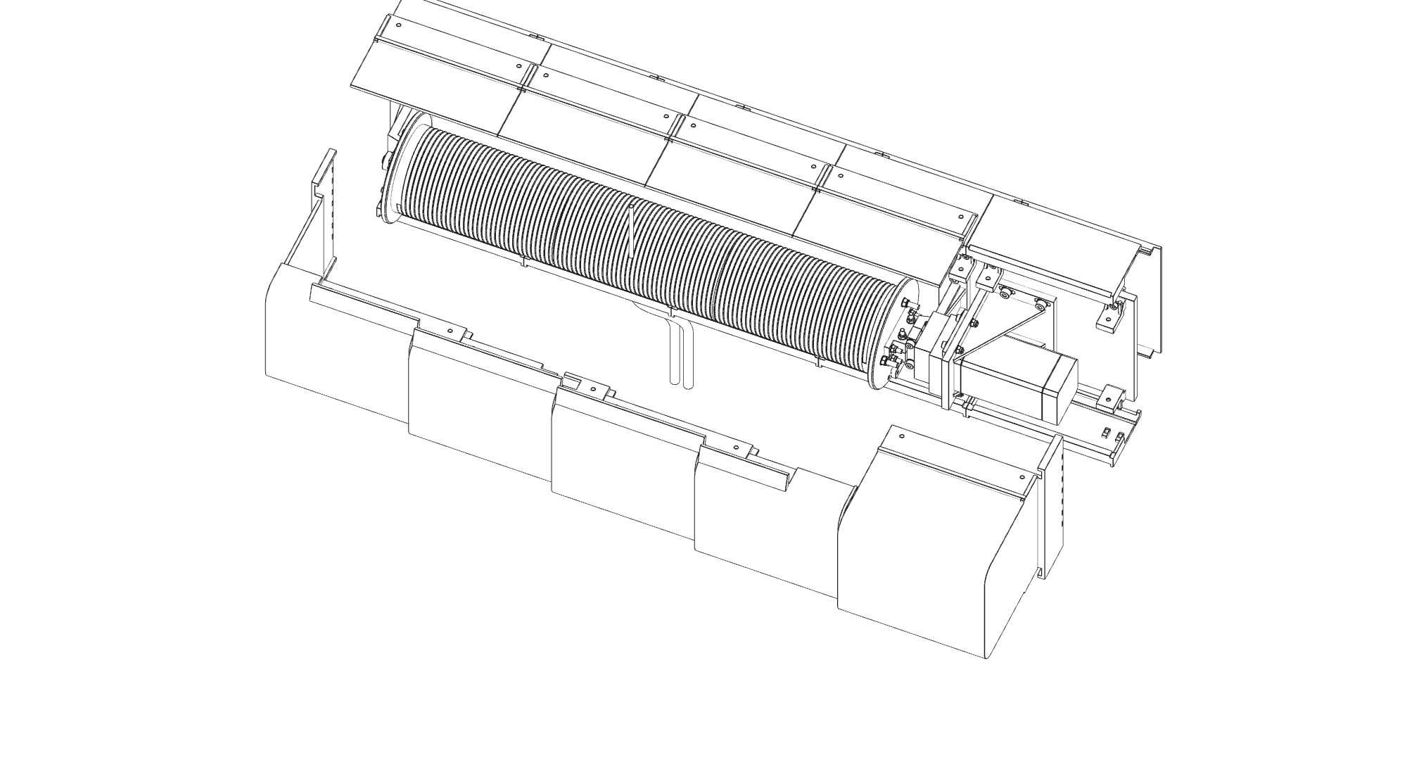
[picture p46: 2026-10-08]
docs/assemblies/winch/booklet/cover-powered-exploded.png

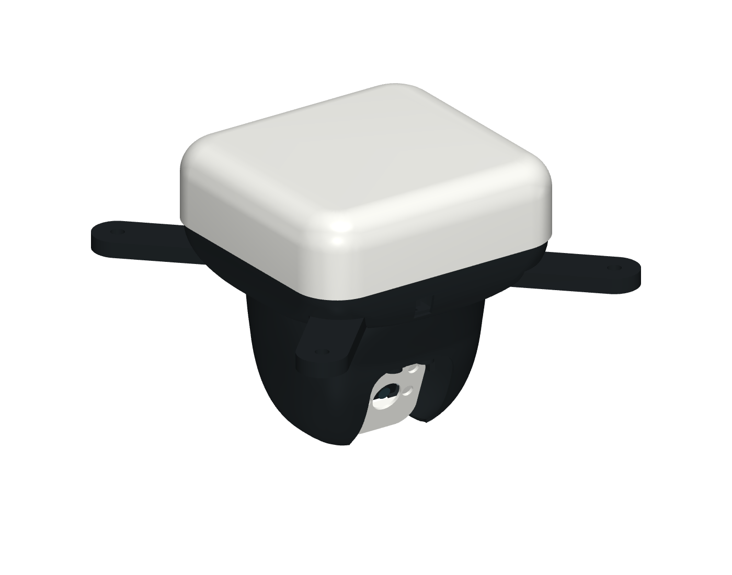
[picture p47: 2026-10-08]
docs/assemblies/camera-pod/enclosure/assembled-cad.png

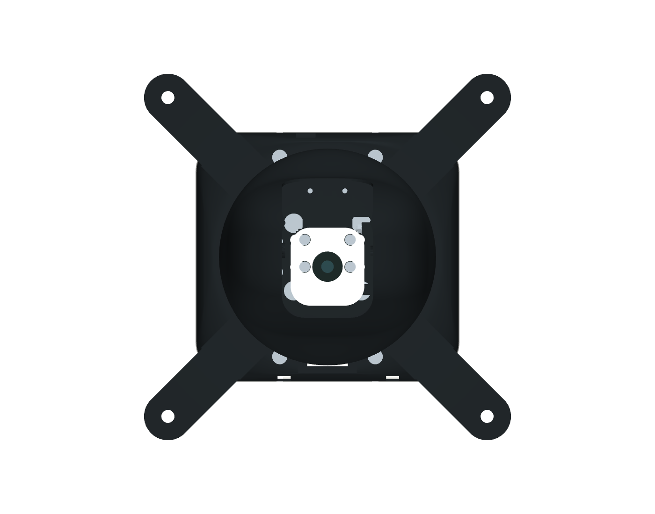
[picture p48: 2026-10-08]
docs/assemblies/camera-pod/enclosure/compact-bottom-cad.png

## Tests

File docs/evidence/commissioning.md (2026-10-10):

# Commissioning host reference evidence

Status: **source and isolated simulation evidence** for [#40](https://github.com/gredice/arbi/issues/40). The [specification](../software/commissioning.md) owns scope. This is no bench, installed-system or qualified physical acceptance record.

## Named revision and environment

- Record `commissioning-golden-host`, revision `2026-10-10`, referenced by the synthetic calibration evidence.
- Committed input: [fixture](../../apps/arbi-edge-controller/fixtures/commissioning.json), configuration `commissioned-config-1`, calibration `calibration-1`, simulation/test `fixture-run`, fictional `synthetic-site`.
- Full-set digest: `6edd698c30e225686c4e96533534310d9f7061b61be67b460d359651df837aef`.
- Configuration digest: `79fe6c2d1944a2453ad4cde98178d4f6baada58540231e990fde99c70b32292d`.
- Calibration digest: `1ca97f101a4906518f3540b111dd139cbe4b1d9b54f87db5b66d066991dcc3a5`.
- Host: macOS development filesystem, Node.js 24.13.0, pnpm 11.5.2; checks on 2026-10-10–11 using independent SQLite files, child processes and SIGKILL. Signing keys are ephemeral/in-memory; data is fictional.
- Automated reviewer `fixture-reviewer` is fictional. Human engineering/physical review belongs to the PR and subsequent stage acceptance.

## Observations

[Commissioning tests](../../apps/arbi-edge-controller/src/commissioning/commissioning.test.ts) cover signed site capabilities, denial audit, matching local maintenance session/epoch/expiry, closed fields, golden site/bed/plant coordinates/framing, payout direction/HOME references, exact independent approval, immutable revisions and reader/local-limit compatibility.

Failed preparation changes no active device. Failure after one device activates leaves other devices unchanged and normal jobs blocked, with stop available. Explicit recovery finishes the set without reapplying a matching device. A child is killed **after device COMMIT and before response/coordinator persistence**. Reopen stays blocked; fresh enrollment/recovery preserve the original device transaction and reconcile remaining devices/audit without job replay. Changed inspection/firmware or revoked calibration approval latch readiness; metadata restoration alone cannot clear it.

SQLite ownership, atomic state/audit rollback, content verification, device timeout and mid-activation session revocation cover the host failure boundary. [Dashboard tests](../../apps/arbi-dashboard/src/dashboard/server.test.ts) cover scoped engineering status reads, omitted viewer/context data and rejection of cross-site/malformed/secret-bearing projections.

Golden pod positions are `(990,2000,2480)`, `(1190,1750,2480)` and `(990,1500,2480)` mm, with pan `8°`, tilt `-24°`. Optical translation is `(10,0,20)` mm, yaw `10°`, pitch `-5°`, gimbal zeros `(2,-1)°`; no camera/image is involved. All axes yield zero signed turns at HOME; lowering the analytical pose changes payout with the configured direction sign.

## Reproduce

Install pinned dependencies and run from the repository root:

```sh
pnpm lint --filter=@arbi/edge-controller --filter=@arbi/dashboard --filter=@arbi/protocol --filter=@arbi/gredice
pnpm typecheck --filter=@arbi/edge-controller --filter=@arbi/dashboard --filter=@arbi/protocol --filter=@arbi/gredice
pnpm test --filter=@arbi/edge-controller --filter=@arbi/dashboard --filter=@arbi/protocol --filter=@arbi/gredice
pnpm build --filter=@arbi/edge-controller --filter=@arbi/dashboard
pnpm docs:check
git diff --check
```

Protocol tests also run existing independent TypeScript/Python/C references. Native PostgreSQL/browser checks remain separate dashboard integration evidence. Linux confinement, selected cabinet storage power loss, real local authorization/transport and every physical prerequisite remain unverified.

The four-workspace suites passed; their six native PostgreSQL cases and one Linux-only systemd case were skipped by the ordinary host suite. `pnpm --filter @arbi/dashboard test:postgres` separately passed all 11 isolated native PostgreSQL tests on Homebrew PostgreSQL 15.19. The commissioning suite passed all 14 tests, including mounted loopback HTTP routes. Dashboard status tests passed all five tests, and `pnpm --filter @arbi/dashboard test:browser` passed all eight Chromium checks. These results remain source/host evidence.

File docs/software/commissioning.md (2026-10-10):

# Authorized site commissioning

[Issue #40](https://github.com/gredice/arbi/issues/40) adds a **simulation-only local commissioning consumer** in the [edge app](../../apps/arbi-edge-controller/src/commissioning/coordinator.ts). It implements existing edge/local operator ownership from [ADR-0006](../decisions/0006-local-safety-authority-and-instrumentation.md), using [configuration 1.0](configuration.md), [Gredice capabilities](site-authorization.md), [audit 1.0](audit-events.md) and [local jobs](local-jobs.md). The [host record](../evidence/commissioning.md) names the tested synthetic revision. Hardware enrollment, actuation, physical calibration and installed readiness remain disabled.

## Records and coordinate references

The app-owned, closed `arbi.commissioning/1.0` record embeds an unchanged configuration 1.0: surveyed rectangular anchors, site/gimbal frame IDs, hardware/assembly/firmware revisions, signal ownership, workspace/operating limits, calibration/evidence and bed/plant mappings. It adds:

- Four winch axes: distinct registered drum/line component IDs, positive payout direction, effective single-layer radius and HOME payout in mm. Hardware/assembly revisions come from the embedded inventory.
- Camera component, site reference frame, optical-origin translation in mm and yaw/pitch offsets in degrees. This bounded framing model rejects nonzero roll; arbitrary moving extrinsics need a future model.
- Dock component/frame, HOME and PRE-DOCK positions, reduced approach speed and latch debounce. Positions must satisfy the calibrated workspace margin.
- Named optical-position/framing targets with an existing bed and optional matching plant. These are explicit commissioned mappings, not an inferred crop survey.

The full set has its own canonical SHA-256 digest. Configuration/calibration digests remain separate; supplement edits require a new configuration revision. Retained revisions are immutable. Field names encode units; unknown fields/units/versions, incorrect frame IDs, invalid component mappings and out-of-workspace values reject. HOME payout must agree with surveyed anchor-to-dock distance plus line offset within declared uncertainty.

`resolveTarget` subtracts optical-origin translation from requested optical position and subtracts yaw/pitch and gimbal zero offsets from framing angles. Optical/pod positions and corrected angles must satisfy accepted bounds. `resolveLineReference` calculates anchor distance plus offset and signed drum turns relative to HOME using circumference `2πr`. [Golden vectors](../../apps/arbi-edge-controller/src/commissioning/commissioning.test.ts) fix the site/bed/plant and payout conventions. These analytical helpers neither measure pose/tension nor issue motor steps.

## Human and local authority

[CommissioningServer](../../apps/arbi-edge-controller/src/commissioning/server.ts) uses `SiteRequestBoundary`: signed dedicated ARBI bearer credentials, current account/site membership, exact configured browser origins and `x-arbi-request: 1`. Writes require `configuration.write` (site engineer), reads `configuration.read`. Device credentials, viewer/operator roles, UI mode and body-supplied actors cannot grant authority. Boundary decisions are durably audited before mutations; unverified actors are never attributed as authenticated humans.

Every privileged operation also requires an independent **local** maintenance authorization bound to the authenticated human/session, site/realm, current edge boot/session and local authorization ID. Its maximum lifetime is 60 seconds, with current stopped, idle and inhibited interlocks. The request cannot supply it. Signed membership and local authorization are rechecked around each asynchronous device operation and before final commit. Revocation, expiry, clock regression and interlock loss block activation.

Enrollment names only an existing trusted adapter ID. Independent discovery supplies actual component/firmware and boot/session identity, site/realm, protocol/readers and reconciled installed hardware digest. Exactly one edge, Pico and pod must match the configuration. Enrollment changes invalidate readiness. This binds local commissioning inventory; it does not mint or replace separate [cloud enrollment credentials](device-enrollment.md).

## Activation and recovery

Trusted composition independently supplies reviewed **exact full-set digests**, accepted calibration digests, installed inventory, hard limits and forward/rollback readers. Requester-supplied evidence flags cannot populate approvals. The explicit isolated runner supplies the fictional fixture approval; hardware mode and physical evidence scopes reject.

Stage validates the record and current enrollment/compatibility, invokes inhibition and atomically records staged identity with audit intent/decision. Rejected candidates retain identity when structurally valid and a bounded reason. Incomplete activation must be recovered before replacing its staged set.

Activation validates every device transition before dispatch, durably records the activating inhibit, prepares the full exact set on **all** devices, then activates. Each independently persisted journal/report must match current module identity, transaction, configuration/calibration/hardware identities, full-set digest and inhibition. Each report/journal is durably recorded. Only after all current observations agree does the coordinator commit active identity and clear its reconciliation block. This is test-realm configuration readiness; other local job/safety prerequisites still apply.

Failures/timeouts, revocation, module restart, firmware/reader/inventory changes and revoked approval keep normal jobs blocked. Devices may temporarily have different applied versions while the **system remains inhibited**; no atomic distributed rollback is claimed. Local stops precede storage. Failures never select motion, HOME or a previous moving state.

Every coordinator startup inhibits and records restart reconciliation. Explicit recovery under current human/local authorization finishes the exact staged set or reconciles the exact active set. Independent device journals include commits whose response/coordinator record was lost, preserving original request, actor and transaction. A matching committed target is observed rather than reapplied. New module epochs require renewed enrollment; retained histories must agree. Incompatible inventory/readers/limits or missing approval prevent recovery. Recovery restores no jobs or leases; restoring metadata alone cannot clear a latched commissioning block. Changed hardware needs an independently reviewed compatible set/recalibration.

## Persistence and consumers

[CommissioningStore](../../apps/arbi-edge-controller/src/commissioning/store.ts) uses bounded SQLite DELETE journaling, FULL/fullfsync, a 100 ms writer timeout, immutable snapshots/audit rows, content verification and exclusive same-host PID/token ownership. State, actor/session, before/after identities, reason code and audit intent/outcome commit together. Defaults: 512 snapshots, 32 MiB logical records and 16,384 pages. Exhaustion blocks new work; automatic history deletion is unsupported. Budgets remain unqualified host starting points. Hashes/triggers do not protect against storage-owner tampering or dishonest storage firmware.

The durable outbox is authoritative. `flushAudit` appends unchanged events to `@arbi/audit` before recording copy acknowledgement; a crash between them deduplicates the append on retry. Historical boots retain attribution. Authorization records mean authorization only. The final local configuration outcome joins its immutable snapshot and independent device journals; it is not motion/physical validation evidence. Audit upload never advances readiness.

Trusted `EdgeRuntime.composeCommissioning(server)` mounts authenticated `GET /sites/<site>/commissioning/status` and `POST .../{enroll,stage,activate,invalidate,recover}` on the bounded loopback listener. POST includes a bounded `reason` ID; enroll adds `deviceId`, stage adds `set`, other fields reject. No default provider or configuration-file switch supplies authority. The coordinator must use the runtime's current identity. `/readyz` exposes the projection and requires its active digest to match the runtime's loaded applied configuration; changed diagnostic/runtime configuration needs explicit reload and reconciliation.

Composition automatically binds commissioning to `EdgeJobs`; an injected authority cannot omit its inhibit. [Job policy](../../apps/arbi-edge-controller/src/jobs/admission.ts) rechecks readiness/exact digest on admission and every phase; stop remains available without readiness. Existing independent diagnostic/job fixtures retain their explicitly preaccepted synthetic boundary.

The dashboard's trusted `readCommissioning(siteId, signal)` adapter supplies the closed `arbi.commissioning-status/1.0` projection. Protected engineering diagnostics with `configuration.read` show active/calibration, staged/rejected identities and blocking reason. Viewer/context reads omit it. Cross-site, malformed, secret-bearing and contradictory projections fail closed; absent composition shows unavailable. This seam returns no site coordinates/local grant and adds no remote write UI.

## Run and remaining gates

After building dependencies, run:

```sh
pnpm --filter @arbi/edge-controller simulate:commissioning --directory /tmp/arbi-isolated-commissioning
```

This explicit isolated recipe creates disposable signed human sessions and three independent simulation SQLite adapters. No signing keys/credentials are printed or persisted. Output includes `physicalActuationEnabled: false`. An existing directory retains history; restart requires deliberate recovery rather than blindly rerunning fresh activation.

Real pairing/transport, protected local presence inputs, credential provisioning, actual extrinsics, surveys and [physical stage gates](../operations/prototype-and-commissioning.md#local-safety-and-update-gates) remain unverified. SIGKILL tests establish process-crash recovery on the development filesystem, not cabinet power-loss durability or physical stopping.

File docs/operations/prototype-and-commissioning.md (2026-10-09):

# Prototype and commissioning

## Principle

ARBI progresses by reducing uncertainty at the smallest practical scale. A later integrated demonstration does not erase missing component evidence. Each phase records the exact hardware, source revision, configuration, conditions, instruments, results, failures, and reviewer.

## Phase 1 — bench winch

- Acquire the selected closed-loop stepper kit plus representative Dyneema, shaft, bearings, coupling, and controller parts.
- Print one complete winch revision.
- Characterize direct-drive force, speed, acceleration, repeatability, holding, heat, and faults.
- Exercise one-layer winding across the full intended drum width.
- Measure effective radius/length mapping, reversal error, line tracking, and maximum useful tension.
- Test home/reference and bounded recovery after lost position.
- Inspect guards, retention, fasteners, printed creep, bearing load, and failure modes.

**Exit evidence:** an approved mechanical revision and measured operating envelope, not merely visible motion.

## Phase 2 — powered line

- Build a representative hybrid line with two conductors mechanically slack relative to Dyneema.
- Build the rotating slip-ring and stationary/rotating strain relief.
- Run repeated full winding/unwinding cycles under representative bend and tension.
- Inspect conductor fatigue, abrasion, insulation, local stiffness, temperature, and effect on line tracking.
- Measure voltage at maximum extension under the worst expected Pi/camera/servo/Wi-Fi load.
- Exercise open/short/contact-intermittency and branch-protection responses under a controlled procedure.

**Exit evidence:** justified working current/voltage, construction, cycle life or replacement interval, and safe fault behavior.

## Phase 3 — camera pod and dock

- Print and assemble the current [compact camera-pod configuration](../../hardware/assemblies/camera-pod/camera-pod-enclosure.md)
  using its selected kit and revisions. Do not add the archived docking stud or
  historical printed alternatives to that kit.
- Develop the structural docking attachment with the [dock interface package](../assemblies/dock/design-package.md);
  exercise a secured dummy-pod capture/release fixture before real pod integration
  using the [bench plan](../assemblies/dock/bench-test-plan.md).
- Install Pi 3A+, selected converter/capacitor, Camera Module 3, and two selected micro servos.
- Weigh the complete pod and record center of gravity.
- Calibrate pan to approximately ±90 degrees and tilt from straight down toward approximately 70 degrees sideways, bounded by safe limits.
- Verify stable pod voltage under simultaneous worst expected loads.
- Implement and measure stop → gimbal → settle → autofocus → capture.
- Test Wi-Fi transfer, local caching, reset, and command interruption.
- Exercise funnel capture, latch, dock confirmation, release, shelter, drainage, and maintenance access.

**Exit evidence:** accepted mass, power stability, gimbal/camera performance, and dock capture/recovery envelope.

## Phase 4 — small four-cable frame

- Build an approximately 4 × 2 m controlled test rectangle.
- Install four winches, representative pulleys/lines, pod, and a test dock or safe restraint.
- Implement synchronized inverse kinematics and smooth trajectories.
- Validate positive-tension strategy, workspace limits, homing, stopping, and representative fault responses.
- Install fiducials and capture repeatable images at known positions.
- Record motion, line, motor, pod, and image data for simulator comparison.

**Exit evidence:** repeatable integrated operation in a controlled exclusion zone with known residual risks and bounded recovery.

## Phase 5 — full outdoor installation

- Survey the site and update the structural, electrical, environmental, privacy, and maintenance plans.
- Install and inspect four posts and guy anchors.
- Pull-test and resurvey corner structures.
- Install and electrically test cabinet and field distribution.
- Install winches, four lines, pod, dock, and fiducials.
- Load the as-built coordinate/configuration revision.
- Calibrate anchors, line references, safe workspace, bed/plant targets, gimbal, camera, dock, and vision processing.
- Commission in stages with exclusion zones, reduced limits, fault injections, weather checks, and inspections.
- Integrate cloud requests only after local operation is accepted.

**Exit evidence:** complete as-built record, accepted safety case, qualified reviews, operating envelope, inspection schedule, and release tag.

## Local safety and update gates

[ADR-0006](../decisions/0006-local-safety-authority-and-instrumentation.md) and the [local safety interface matrix](../system/local-safety-interface-matrix.md) define required functions and evidence owners. These gates govern authority for the named rig/target/configuration. No gate is passed merely by merging requirements, changing a capability flag or completing a GitHub issue.

| Stage | Entry, scope and exit requirements |
| --- | --- |
| Source/design and simulation | Requirements and fixtures may use simulated or unavailable inputs. Review interface semantics and fault scenarios; label every result as source/model evidence. No physical actuation or field activation authority follows. |
| Secured isolated bench/HIL | Explicit authorization under a reviewed test procedure for the exact target, wiring, fixture and configuration. Disconnect operational actuator loads or use secured controlled substitutes/restraint; define reduced travel/speed/force/time, exclusion zone, accessible isolation, initial output states and stop conditions. Actuation/flashing may produce B evidence before installed gates pass. Actual target timing and electrical response are measured; substitute-input tests cannot validate absent sensors or loaded restraint. |
| Secured loaded frame | Accept relevant component/interface B evidence, rig structural/electrical hazards, independent stop path, restraint, calibrated force/position/clearance measurements and test-specific fault/recovery procedure before applying load. Measure the LS fault matrix under reduced limits and controlled access. The test rig's acceptance does not enable unattended or installed operation. |
| Installed operational actuation | Disabled until the as-built installation has required B/F/I evidence, approved local configuration/calibration, independent protections, measured line tension/clearance, power-loss response, local weather/access policy and applicable Q reviews. Missing mandatory observations or limits block the affected capability. |
| Loaded/installed motion-controller updates | Disabled until that stage's target-specific LS-18 restraint/clearance evidence and LS-03/08/12/16/17 reset/isolation/recovery prerequisites are accepted. `Parked`, zero commanded speed or a signed artifact is insufficient. Conflicting motion/manual/maintenance work is locked out; interrupted update/reset cannot automatically restore commands. Edge/pod restarts also need their own reviewed outage/recovery procedure. |
| Public operation and return to service | Release evidence index, qualified acceptance, residual-risk/inspection/recovery procedures and deliberate local authorization for the released installation. Material hardware/firmware/configuration/calibration changes invalidate affected evidence and require retesting before restoring authority. |

All physical gates above are currently **unverified**. Source checks, simulator assertions and ordinary documentation review do not constitute instrumented bench/HIL, loaded-frame, installed-site or qualified physical-safety review. [#59](https://github.com/gredice/arbi/issues/59), [#67](https://github.com/gredice/arbi/issues/67), [#76](https://github.com/gredice/arbi/issues/76), [#78](https://github.com/gredice/arbi/issues/78) and [#79](https://github.com/gredice/arbi/issues/79) carry the implementation/evidence follow-ups.

## Test-record minimum

Every committed evidence record should include:

- test identifier, purpose, linked requirement/issue, and date;
- part/assembly/build/software/configuration revisions;
- setup diagram or photos safe for public release;
- environmental and initial conditions;
- calibrated instruments and measurement uncertainty where relevant;
- exact procedure and stop conditions;
- raw data location and analysis version;
- result against predefined acceptance criteria;
- anomalies, damage, follow-up, and reviewer.
- applicable LS requirement IDs, authorized stage/rig scope, measured fault-detection/response times, stopping distance/force and line-clearance results where relevant, and any evidence still missing before the next stage.

Do not replace raw data with a screenshot when machine-readable measurements exist.

## Commissioning rules

- Begin at reduced speed, acceleration, force/current, workspace, and access.
- Validate one hazard/control at a time when practical.
- Keep people outside loaded and moving envelopes.
- Stop on unexpected noise, motion, heat, smell, deformation, line damage, low clearance, moisture, or sensor disagreement.
- Never bypass a safeguard just to finish a test.
- After any structural, electrical, line, drum, pod, dock, firmware, or calibration change, rerun affected acceptance tests.
- Simulation may predict tests but cannot authorize a higher hardware limit.

## Open engineering questions carried into testing

- Final post and anchor design for the real soil/wind environment.
- Final pulley and drum size.
- Maximum line tension, speed, acceleration, and parking tension.
- Powered-line conductor and slip-ring life.
- Converter/servo selection, pod mass, and settling interval.
- Need for IMU, tension sensing, controlled lighting, differential signals, and fail-safe brakes.
- Final dock geometry and power-loss response.
- Final per-bed/plant mapping and fiducial system.

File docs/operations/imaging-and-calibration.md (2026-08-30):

# Imaging and calibration

## Operating intent

ARBI supports scheduled sweeps and on-demand bed or plant captures. Both modes use the same local safety checks, coordinate mapping, motion, gimbal, focus, rectification, storage, and reporting sequence. Priority affects queue order, not safety behavior.

## Capture sequence

```mermaid
flowchart TD
    REQ["Scheduled or on-demand request"] --> MAP["Map bed/plant to XYZ and framing preset"]
    MAP --> CHECK["Validate state, workspace, configuration, and operating policy"]
    CHECK --> MOVE["Move Skycam to coarse position"]
    MOVE --> STOP["Stop Skycam motion"]
    STOP --> GIMBAL["Move pan/tilt to requested framing"]
    GIMBAL --> SETTLE["Wait measured settling interval"]
    SETTLE --> AF["Run autofocus"]
    AF --> CAP["Capture image and metadata"]
    CAP --> RECT["Rectify using calibrated camera and fiducials"]
    RECT --> STORE["Cache/upload and return result"]
```

The current settling range is approximately 100–300 ms. It is a starting point. Measure representative large and small gimbal moves and increase the interval when needed.

For a normal capture:

- do not reposition the gimbal while the Skycam is moving;
- do not autofocus until Skycam and gimbal motion have stopped and settling time has elapsed;
- do not interpret upload success as capture or motion success;
- keep raw capture, calibration revision, requested/estimated pose, timestamps, and health metadata sufficient to reproduce processing decisions.

## Scheduled sweep

The 30-bed target can use pre-calibrated bed centers and one or more named framing presets per bed. A sweep planner should minimize unnecessary travel while preserving local safety limits, image timing needs, and return-to-dock policy. A stale schedule cannot override maintenance, fault, weather, or exclusion controls.

## On-demand capture

An on-demand request identifies a bed or plant, not an unvalidated motor coordinate. The local edge service resolves the request through versioned site and framing configuration. A plant close-up may select a different X/Y target and pan/tilt preset. Lower-Z motion is permitted only when separately validated for current crop and line clearance.

## Motor homing

Each winch has a home/reference switch. The current recovery concept is:

1. after position loss, move each winch slowly toward a known reference using a bounded homing strategy;
2. establish the spool-angle reference;
3. transform the references into calibrated line-length coordinates;
4. verify that the resulting pose and line state are plausible before entering normal readiness.

The final procedure must define axis order or coordination, direction, reduced force/speed, independent limits, timeout, switch repeatability, cable-tension constraints, failure recovery, and whether the pod must be docked or otherwise restrained. Homing must not create excessive tension or slack.

## Geometric and mechanical calibration

Calibration should distinguish:

- surveyed anchor tangent coordinates;
- home-switch offsets and motor direction;
- steps/encoder counts per drum revolution;
- drum effective radius and helical line-position effects;
- termination offsets and line reference length;
- line elasticity, creep, sag, and temperature effects where significant;
- cable-spider, gimbal, and camera transforms;
- dock PRE-DOCK and capture geometry;
- bed and plant target coordinates.

Every calibration set records the compatible site, line, drum, pod, dock, and software revisions. Replacing or altering a line, drum, termination, pulley, anchor, camera, or gimbal requires a documented compatibility decision and usually recalibration.

## Vision calibration and rectification

Permanent fiducials around the bed area should help estimate actual X/Y offset, camera rotation, perspective tilt, and scale. The result can rectify an image into a consistent canonical bed view even when mechanical positioning differs by a few centimeters.

The vision process needs:

- selected fiducial family, printed size, material, placement, and coordinate survey;
- camera intrinsics and distortion calibration for the released module/focus behavior;
- detection confidence and minimum geometry;
- rejection rather than silent rectification when evidence is insufficient;
- representative tests across sunlight, shadow, wetness, dirt, crop occlusion, camera angles, and aging;
- a method to distinguish camera/pod displacement from fiducial/site movement.

Vision correction reduces the need for expensive mechanical precision but does not make unsafe motion or unknown geometry acceptable.

## Image identity and repeatability

Each result should identify:

- request/job and bed/plant target;
- capture time and clock quality;
- site, calibration, framing, hardware, and software revisions;
- requested pose and relevant estimated/observed pose;
- gimbal command and actual/estimated state available;
- settling interval and autofocus result;
- raw image identity, processed image identity, and rectification status;
- health/fault warnings and whether upload was delayed.

Repeatability acceptance must specify measurable spatial/framing/focus metrics rather than visual impressions alone.

## Offline and failure behavior

Loss of Internet should not invalidate local motion safety. The edge service may cache completed captures and upload later. Failed focus, capture, rectification, or upload should return distinct outcomes and bounded retries; it should not trigger repeated motion indefinitely. A capture failure still ends in the configured idle/docking policy unless a fault requires a different controlled response.

## Acceptance evidence

- Homing repeatability and bounded failure behavior across every axis.
- Coordinate and calibration round-trip tests with known reference vectors.
- Motion arrival error and image rectification error at representative center, edge, and close-up targets.
- Gimbal range, repeatability, measured settling, focus, and framing results.
- Scheduled and on-demand flows with delayed, duplicate, stale, interrupted, and offline requests.
- Raw/processed image and metadata traceability without leaking secrets or unintended private imagery.
- Demonstrated invalidation after incompatible hardware or calibration changes.

## Open questions

- Final per-bed and per-plant target model and framing presets.
- Fiducial family, size, number, placement, weather life, and cleaning/replacement plan.
- Required whole-bed and close-up image quality and repeatability metrics.
- Time synchronization between cloud, edge, MCU, and pod.
- Whether an IMU improves settling detection enough to justify its mass and integration cost.
- Privacy masks, retention, public visibility, and handling of incidental people in images.

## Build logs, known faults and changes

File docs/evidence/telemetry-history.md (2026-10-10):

# Telemetry history host evidence

The [bounded current/history contract](../software/telemetry-history.md) implements the isolated simulation adapter allowed by [#37](https://github.com/gredice/arbi/issues/37). It uses the merged enrollment, authorization, jobs and realtime foundations and the external PostgreSQL boundary selected by [ADR-0005](../decisions/0005-software-architecture-and-deployment.md).

## Committed executable records

- [Shared telemetry cases](../../apps/arbi-dashboard/src/telemetry/test-support.ts) run against both embedded PostgreSQL and native PostgreSQL: boot/reset/gap/late/replay ordering; preserved zero versus unavailable null; partial-update age; source-clock uncertainty; configuration/capability barriers; fault raise/clear and late detail; trace idempotency, linkage and duration; assembly pagination/redaction; keyset cursor/filter binding and later-admission exclusion; request/range/page budgets; all five tier row caps and raw-to-aggregate persistence.
- Retention predicates execute in both databases at a frozen trusted clock boundary: exactly the age cutoff remains eligible and one millisecond older is deleted. Only the clock read is isolated; row retention, constraints and deletes execute in PostgreSQL.
- [Native checks](../../apps/arbi-dashboard/src/telemetry/postgres.test.ts) add independent connections, concurrent duplicate ingestion counted once, durable state across replacement service instances, injected realtime failure rolling back raw/aggregate/current/replay together, inventory row lock deadlines, and authenticated HTTP handler/proof/origin/query checks against real migrated SQL.
- [Runtime tests](../../apps/arbi-dashboard/src/telemetry/http.test.ts) and the [built Next.js HTTP launcher](../../apps/arbi-dashboard/scripts/test-http.mjs) exercise redacted, uncached unavailable responses on all unconfigured telemetry routes. Additive migration 0006 is applied twice in the database suites.

On 2026-10-10–11 the local implementation was checked with Node 24.13.0, pnpm 11.5.2 and isolated native PostgreSQL 15.19 (Homebrew). The dedicated launcher owns/removes a temporary Unix-socket-only cluster and creates a separate telemetry database. Test identities, signatures, inventories and observations are synthetic; no deployment credentials, real installation data or provider resources are used. CI separately validates the committed source on its pinned Linux environment.

## Limits of this record

These tests establish source behavior and isolated host database/HTTP evidence. They do not establish provider provisioning, ingestion throughput under a commissioned workload, measured mobile bandwidth, power-loss durability or physical sensor accuracy. Live routing/deployment/mobile acceptance remains open under [#29](https://github.com/gredice/arbi/issues/29); this issue explicitly allows its isolated adapter work before live enablement. An operator must provision trusted identity/database composition, runtime grants and hourly idle-site retention maintenance before activation. Motion permission, command execution and all physical commissioning gates remain separate facts.

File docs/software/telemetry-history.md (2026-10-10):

# Current state and bounded telemetry history

This implements the simulation/isolated-adapter scope of [#37](https://github.com/gredice/arbi/issues/37) under [ADR-0005](../decisions/0005-software-architecture-and-deployment.md). The [telemetry service](../../apps/arbi-dashboard/src/telemetry/server.ts) uses the enrolled edge identity, current site/account authorization, PostgreSQL and transactional [realtime hints](realtime-recovery.md). [Host evidence](../evidence/telemetry-history.md) is separate from live provider provisioning, mobile measurements and physical validation.

## Composition and authority

Protected server composition calls `createTelemetryServer` and `configureTelemetry` with the same database, realm, Gredice identity/resource resolver, current-authority resolver and approved browser origins as [cloud jobs](command-jobs.md). The resolver must read current session, membership, account/site and capability state and honor cancellation; returning a persisted context is insufficient. Humans are authorized and audited by the existing HTTP boundary, then checked again under the inventory lock before and after the protected query. Missing composition returns a redacted private/no-store 503. Production realms, hardware scopes and service principals are denied.

Only a currently enrolled, active edge with current applied configuration and an unexpired/unrevoked Ed25519 credential can upload. The proof binds all envelope fields, including the configuration revision. Boot/session identities are adopted by enrollment, never by a telemetry message. Old boots, revoked credentials, foreign sites/realms and unnegotiated capabilities are denied. Telemetry needs a current-source/configuration `state.snapshot` with matching advertised capabilities, admitted either through this service or the jobs snapshot route. Pico/pod physical inventory remains in the enrollment registry; the edge owns this cloud upload boundary.

Ingestion, retention and reads share the inventory-first transaction order with enrollment, jobs and realtime. Current state, raw history, both aggregate tiers and the realtime head/outbox commit atomically. Failed storage or hint admission returns unavailable and rolls back all changes. These observational tables are mutable and distinct from immutable [audit/job evidence](audit-durability.md). Historical deletion never deletes those records or grants execution permission.

Apply additive [0006-telemetry.sql](../../apps/arbi-dashboard/migrations/0006-telemetry.sql) after migrations 0001–0005 with `pnpm --filter @arbi/dashboard db:migrate:telemetry`. Supply `ARBI_TELEMETRY_DATABASE_URL` privately to the operator process. Runtime roles require SELECT/INSERT/UPDATE/DELETE on the three telemetry tables and USAGE/SELECT on their identity sequence, registry SELECT/row locking, job site SELECT/INSERT/UPDATE, job receiver SELECT, existing authorization audit grants and realtime trigger table grants. PUBLIC receives no rights. Migration ownership and DDL rights must not be the runtime role. Configure finite pool acquisition/connect deadlines; SQL uses a 1.5-second statement deadline, a one-second lock deadline and the existing four-second transaction clock guard.

## Ingestion and truthful current state

`POST /api/sites/:siteId/telemetry/device` accepts exactly `version`, `realm`, `siteId`, `deviceId`, `credentialId`, `identity`, `configRevision`, `issuedAtMs`, `expiresAtMs`, `action`, `payload`, `signature`. Version is `arbi.telemetry/1.0`; the signed proof uses the existing enrollment canonical proof bytes. Its lifetime is at most ten seconds. Requests have no browser Origin or bearer header. JSON is capped at 60,000 bytes with the existing five-second body-read deadline. No private key crosses the API.

For `action: ingest`, payload is one validated arbi/1.0 telemetry or event envelope, with null client ingest time and simulation execution mode. Source UTC/uncertainty, boot/session, uint64 sequence, monotonic sample times, units, frames, quality and configuration/capability context are retained. The receiver supplies receive time and ingest time with its configured uncertainty. Protocol events retain full body detail, including fault ID, raised/cleared state, severity and error code. Copied command outcomes are historical observations only; the [jobs outcome API](command-jobs.md) still owns job reconciliation and audit effects.

Each device has independent telemetry/event high-water marks. A higher sequence with regressing source/sample monotonic time is rejected. Exact current duplicates return `duplicate`; contradictory current or retained stream sequences and retained event IDs return conflict. Canonical stream/group hashes are independent of JSON property order. Lower sequences are retained as `late` raw/event detail without replacing current state, fault state or aggregate counts. Retained late keys deduplicate; contradictory retained keys conflict. Once raw/detail retention expires, an old replay can be retained again as late detail, still without changing current state or aggregates. Advancing gaps report the missing sequence count. A negotiated boot/session change clears incompatible readings/snapshot/fault projections and increments a persisted reset count. Cumulative gaps remain visible even if later backfill arrives: they describe what the current-state stream missed at admission. `coverage.startKnown: false` explicitly avoids claiming complete pre-attachment history.

Partial telemetry updates preserve other metrics with their own source/receive provenance and age. A numeric zero remains numeric zero. An unavailable measurement retains null value and its reason; it never contributes a numeric zero to aggregates. Current freshness uses conservative source-to-receiver delay plus elapsed receive time and sample age, with a five-second maximum. Unknown/inconsistent UTC uncertainty makes numeric readings stale. Stale readings preserve their origin quality. Current identity/configuration mismatch or a newer negotiated capabilities revision invalidates freshness. Current reads consider both telemetry-service and job-receiver snapshots; a capabilities change clears incompatible partial readings on the next advancing telemetry message. Event snapshot freshness is separate from the latest event’s freshness, so a fresh fault update cannot make an old Ready snapshot current. Callers must continue aging data after `observedAtMs`; absent readings and stale/unknown coverage supply no measurement or operating permission.

## Enforced retention and downsampling

These are upper bounds **per site across all devices, configurations, boots and qualities**. Age and row limits both apply; high cardinality can evict data before its maximum age. No complete history is promised.

| Tier | Maximum age | Maximum rows | Meaning |
| --- | --- | --- | --- |
| `raw` | 24 hours | 4,096 | One detailed sample/provenance row per metric, including explicitly late data |
| `minute` | 7 days | 8,192 | 60-second receive-time buckets for advancing samples |
| `hour` | 90 days | 8,192 | 3,600-second receive-time buckets for advancing samples |
| `event` | 90 days | 4,096 | Full protocol event detail; searchable faults and late observations |
| `trace` | 7 days | 32 | Explicit small diagnostic attachments linked to a retained event |

Both aggregate tiers are updated directly at ingestion, independently of raw retention. Grouping separates source boot/session, configuration/capabilities revision, metric, unit, frame, effective quality, origin quality and reason. Counts, numeric counts, sum/mean/min/max, reported uncertainty maximum, unknown uncertainty/age counts, first/last source and receive times and gap counts are retained. Unavailable-only groups have null numeric statistics. Commanded, estimated, measured and stale data are never silently averaged together. Aggregate quality records freshness at admission; it is not a live sensor assertion. Bucket age is measured from the receive-time bucket start, so a bucket can expire up to one bucket width before its last sample. Row eviction uses creation order, not device clocks.

Every successful ingest prunes expired/excess rows before and after admission. Current heads are capped at 64 streams (32 device pairs); obsolete device heads are removed by pruning. A fault projection retains up to 64 IDs per device, evicting the oldest cleared fault before refusing excess active faults. Detailed fault history retains its separate event policy. Read predicates exclude expired history even when a site is idle. For physical expiry on idle sites, an operator invokes `pnpm --filter @arbi/dashboard telemetry:maintain` for one known site with private `ARBI_TELEMETRY_DATABASE_URL` and explicit `ARBI_TELEMETRY_ENVIRONMENT` (`test` or `preview`), `ARBI_TELEMETRY_NAMESPACE`, `ARBI_TELEMETRY_SITE_ID`. Provision a once-per-hour site invocation when enabling the service; no all-site scan, scheduler or provider resources are installed by this change. An idle database can retain expired rows until that invocation, while query access still enforces expiry and row growth remains capped.

For `action: trace`, payload is exactly `traceId`, `eventId`, `messages`. The linked event must be retained and match the current source/configuration. Attachments have at most 128 validated telemetry messages, 512 samples and ten seconds of source monotonic duration within the 60,000-byte request budget. Sequences and sample times advance inside the attachment. A trace does not update current state or statistical history. It is stored as private bounded JSON in PostgreSQL, without a public object URL or arbitrary file upload. An identical retained trace is idempotent; a contradictory ID conflicts. This small attachment budget avoids an unbounded high-frequency recorder.

## Filtered and paginated APIs

All reads use `/api/sites/:siteId/telemetry/:action`, current ARBI bearer authorization and private/no-store responses. Numeric query strings must be nonnegative decimal integers; duplicate or unknown parameters are rejected. Responses carry an observation time, explicit provenance and coverage. No credentials, provider exception or identity directory internals are returned.

| Action | Permission | Query and result |
| --- | --- | --- |
| `current` GET | `state.read` | Optional `deviceId`, `limit` (default 8, maximum 32 streams), `after`. Returns states/readings with source times, units, qualities, age bounds, identity/config compatibility, gaps/resets and next cursor. |
| `inventory` GET | `diagnostics.read` | Optional `assemblyId`, `after`, `limit` (default 25, maximum 100). Returns canonical configured assembly/hardware IDs and revisions, signal ownership/availability/units and redacted enrolled device status/software/config/freshness. This is configured inventory, not a new BOM or installed-inspection claim. |
| `history` GET | `history.read`; `diagnostics.read` for traces | Required `tier`, `fromMs` inclusive, `toMs` exclusive, `limit` (1–100). Optional `cursor`, `deviceId`, `configRevision`; raw/aggregate filters `metric`, `quality`; event filters `faultId`, `severity`, `eventType`; trace filter `traceId`. |

History range cannot exceed the selected tier’s retention horizon and is clamped to the current age cutoff. `next` is an opaque versioned keyset cursor bound to the realm/site and exact filters/page size. It bounds the initial admission ID and excludes later new rows; there are no offsets or unbounded exports. Pages are newest admission/aggregate-creation first, not chronological source time. Aggregate values can evolve and retention can remove rows between pages; this is a bounded observational view, not a frozen export. Current/inventory `next` feeds their `after` parameter; callers retain the original filters and treat inventory configuration changes as a reason to restart pagination.

Every site has persisted fixed-minute successful request budgets: 600 ingestion, 10 trace and 120 protected reads. Invalid/rejected transactions roll back their mutation; accepted calls consume the shared budget across processes and principals. Capacity returns 429; oversized successful response candidates are capped at 256,000 bytes and require a smaller page. These application budgets and byte counts are not measured mobile traffic or provider billing. History scans are bounded by hard table caps and SQL deadlines; no public SQL or cursor value supplies authorization.

Validate with `pnpm docs:check`, dashboard lint/typecheck/test/build, `test:postgres` and `test:http`; existing browser checks cover the surrounding authenticated shell/recovery foundation. This API foundation does not add a telemetry chart to the shell or automatically activate a live provider.

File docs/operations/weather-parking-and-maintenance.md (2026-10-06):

# Weather, parking, and maintenance

## Operating policy

The pod returns to its high HOME dock whenever it is inactive. The dock is the primary weather shelter; the pod rain cap is only brief splash/direct-rain protection.

The V1 baseline deliberately does not use an anemometer or numeric wind-based operating limit. At the same time, it says not to start work when adverse weather is expected or observed. The mechanism that makes that decision is currently undefined. Until a validated local policy or sensing/integration exists, inability to determine acceptable conditions is a stop condition.

## Inactive and weather sequence

```mermaid
flowchart TD
    IDLE["Capture complete or inactive"] --> RETURN["Return toward HOME"]
    WEATHER["Adverse or unknown conditions"] --> REJECT["Reject new captures"]
    REJECT --> ABORT["Complete or abort current move safely"]
    ABORT --> RETURN
    RETURN --> DOCK["Slow PRE-DOCK approach and latch"]
    DOCK --> CONFIRM["Confirm mechanical capture"]
    CONFIRM --> PARKED["Park with only approved line tension"]
```

Strong wind, lightning risk, rain beyond the approved pod exposure, ice, visibility loss, unusual line motion, or other conditions outside the validated envelope prohibit a new normal capture. The safe response to a condition first detected during motion must be defined by scenario; “always go home” is not safe if the path or dock has become unavailable.

## High parking versus ground-level service

Normal automatic parking remains at the high dock:

- target capture point approximately 2.65–2.70 m;
- target bottom of docked pod approximately 2.4–2.5 m;
- the pod stays out of normal head space while inactive.

Servicing without a ladder is handled separately. A manually initiated `Maintenance` state may lower the pod only after:

1. the work area is physically cleared and controlled;
2. remote and scheduled jobs are inhibited;
3. stored mechanical/electrical energy and recovery behavior are understood;
4. an operator intentionally authorizes the move;
5. the system uses reduced, bounded motion to an approved service position;
6. isolation/lockout is applied before hands enter hazardous areas.

The controller must never enter below-head-height maintenance positioning automatically. Failure recovery must not improvise a low position.

## Parked line policy

V1 does not intentionally slack the four positioning lines. Repository starting values are:

- minimum line height over accessible work or walking areas: at least 2.2 m;
- initial parking-tension experiment: approximately 10–20 N per line;
- actual value chosen from installed measurements, with special attention to the heavier powered line.

The dock latch supports the pod, while the powered winches currently preserve line clearance. Because a normally engaged brake is deferred, total-power-loss line sag is unresolved. Public operation may require bringing a fail-safe brake or other passive clearance control into V1.

## Weather readiness

Before each operating period, confirm:

- conditions are inside a locally defined, evidence-backed envelope;
- no lightning or surge-related stop condition is active;
- lines, posts, guys, anchors, dock, and shelter show no storm damage;
- the pod, dock, pulley keepers, and enclosures are dry/drained enough for approved operation;
- fiducials and optical surfaces are visible and usable;
- no ice, debris, plant growth, or foreign object enters a line, winch, dock, or workspace;
- site access and exclusion controls are effective.

Remote weather forecasts may be one input but cannot prove local line/wind conditions.

[LS-14 and LS-15](../system/local-safety-interface-matrix.md#required-measurements-and-permission-inputs) assign local weather/access permission, validity and failure behavior. The BOM's weather-sensor entries are deferred, not evidence of fitted sensors; this requirement does not change V1's anemometer selection. A reviewed local observation/inspection or sensing policy must define the accepted envelope and expiry. Weather readings remain unavailable until a reviewed interface and measurements exist; unknown conditions inhibit dependent operation.

## Routine inspection

Define intervals by elapsed time, travel/cycle count, exposure event, and observed condition. At minimum inspect:

- posts, soil movement, guys, anchors, brackets, backing plates, bolts, shackles, pulleys, and corrosion;
- Dyneema, powered conductors, terminations, guides, slip ring, sag, and calibration drift;
- drums, couplings, bearings, guards, home switches, motors, drivers, and abnormal sound/heat;
- pod chassis, line attachments, docking stud, gimbal, ribbon, fasteners, converter, capacitor, connectors, cap, and optics;
- dock arm, funnel, latch, spring, pins, release, sensor, roof, drainage, and debris;
- cabinet protection, seals, terminals, earthing/bonding, labels, moisture, heat, and event logs;
- fiducials, site reference points, paths, privacy/exclusion zones, and vegetation encroachment.

Every inspection identifies the released assembly revisions and records pass, measured result, observation, action, and reviewer. “Looks fine” is not enough for critical discard criteria.

## Maintenance controls

- Prevent remote, scheduled, or automatic start during maintenance.
- Isolate and verify relevant electrical energy.
- Control line tension and mechanical stored energy before opening guards or removing parts.
- Never work below suspended hardware or loaded test equipment.
- Recalibrate after changes that affect geometry, line length, drum radius, camera, gimbal, anchors, or dock.
- Run bounded post-maintenance tests before restoring the full operating envelope.
- Replace parts by stable ID and compatible revision, not appearance alone.

## Return to service

Return to service requires:

- completed work and inspection records;
- all guards, retention, protection, seals, and labels restored;
- compatible configuration/calibration loaded;
- no unresolved critical observation;
- safe homing/recovery and dock test at reduced limits;
- required electrical or structural retest;
- deliberate release from maintenance by an authorized operator.

## Acceptance evidence

- Defined local environmental operating and parking envelope.
- Reliable rejection of new work and bounded response to weather changes during each state.
- Repeated high docking and safe manually controlled maintenance access.
- Measured parked line clearance in normal and relevant fault/power conditions.
- Inspection intervals and discard criteria supported by material/component evidence.
- Demonstrated remote-start inhibition, isolation, lockout, and post-maintenance release.
- Storm/event inspection and recovery procedure.

## Open questions

- How are acceptable wind, rain, lightning, temperature, and ice conditions determined locally?
- What is the safe action when the dock is inaccessible during deteriorating weather?
- Is passive braking required to preserve line clearance through total power loss?
- Which inspections can use telemetry, and which require physical access and measurement?
- What maintenance position and restraint provide safe ground-level service?
- How often do UV-exposed line and printed parts require replacement?

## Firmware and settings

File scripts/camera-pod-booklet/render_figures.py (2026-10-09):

"""Render the actual camera pod mount STLs and the exact checked assembly transforms."""
import json,copy
from collections import Counter
import numpy as np
import vtk
import mesh_renderer as v
from mesh_renderer import render
from integration import assembly,T,R,ROOT,BLUE,GRAY,DARK,GREEN,ENCLOSURE,ARTIFACT,BLACK,WHITE,CONFIG

def tint(name,kind):
 pd=v.polydata('models/reference/'+name+'.stl');colors=vtk.vtkUnsignedCharArray();colors.SetNumberOfComponents(3);colors.SetName('part_colors')
 for i in range(pd.GetNumberOfCells()):
  cell=pd.GetCell(i);x,y,z=np.mean([pd.GetPoint(cell.GetPointId(j)) for j in range(cell.GetNumberOfPoints())],axis=0);rgb=(45,125,82)
  if kind=='pi':
   x+=32.5;y+=28
   if z<0 or z>1.62:rgb=(168,177,181)
   if z>1.62 and 23<=x<=37 and 24<=y<=38:rgb=(53,60,67)
   if z>1.62 and y>=49:rgb=(48,53,57) if z<4.21 else (183,149,70)
   if z>1.62 and 42<=x<=45 and 4<=y<=25:rgb=(218,221,215)
  elif kind=='camera':
   if z<0:rgb=(196,198,181)
   elif z>5.56:rgb=(68,91,113)
   elif z>1.13:rgb=(45,50,57)
  elif kind=='buck' and z>1.62:rgb=(61,72,80)
  colors.InsertNextTuple3(*rgb)
 pd.GetCellData().SetScalars(colors)

def shift(parts,fn):
 out=copy.deepcopy(parts)
 for p in out:p['matrix']=(fn(p)@np.array(p['matrix'])).tolist()
 return out

# Whole-assembly teardown along the spider axis, in assembly order. Published as the
# overview-exploded figure; the public site reads its transforms from figure-manifest.json.
OVERVIEW_LAYERS=[(('rain-hood','electronics-cover'),('cover-nut-','cover-top-washer-'),215),(('pi','converter','capacitor'),('pi-','converter-','capacitor-'),140),
 (('deck',),('frame-upper-washer-','frame-nut-'),95),(('enclosure-base',),('cover-bolt-','cover-bottom-washer-'),52),((),('spider-spacer-',),22),
 (('pan-mount','pan-servo'),('pan-servo-','frame-bolt-','frame-lower-washer-'),-44),(('pan-fairing','gimbal-head'),('fairing-','head-'),-92)]
OVERVIEW_GROUP={'fixed':0,'pan':-150,'tilt':-196}
# The outer head has its own layer; internal pan parts remain on the carrier layer.
# Moving-part details repeat the pivot, horn and camera figures at larger spacing.
OVERVIEW_DETAIL=[('tilt-servo-boot','boot-',(-66,0,0)),('tilt-pivot-support','pivot-support-',(42,0,-16)),('camera-cowl','camera-cowl-nut-',(0,0,35)),
 ('camera-hood',None,(0,0,-42)),('camera',None,(0,0,-19)),('pan-horn-retainer',None,(0,0,24)),('pan-horn',None,(0,0,11))]

def overview_ex(p):
 n=p['name']
 for names,prefixes,z in OVERVIEW_LAYERS:
  if n in names or n.startswith(prefixes):return T(0,0,z)
 x,y,z=0,0,OVERVIEW_GROUP[p['group']]
 for name,prefix,(dx,dy,dz) in OVERVIEW_DETAIL:
  if n==name or (prefix and n.startswith(prefix)):
   if ENCLOSURE and name=='tilt-pivot-support':dz=0
   x,y,z=x+dx,y+dy,z+dz;break
 return T(x,y,z)

def main():
 for name,kind in [('raspberry-pi-3a-plus-reference','pi'),('camera-module-3-standard-reference','camera'),('buck-converter-UNVERIFIED','buck')]:tint(name,kind)
 allparts=assembly();openparts=assembly(cover=False)
 if ENCLOSURE:
  openparts=[p for p in openparts if p['name'] not in ['enclosure-base','gimbal-head'] and not p['name'].startswith('head-')]
 render('assembled-open',assembly(cover=False),direction=(.55,-1,.55),size=(1600,1350))
 # At tilt 0 the optical axis points down; tilt 55 presents the camera face.
 # Retain a separately named neutral inspection view and neutral GLB/manifest.
 render('assembled-covered',assembly(0,55) if ENCLOSURE else allparts,direction=(.7,1,.4) if ENCLOSURE else (.7,-1,.48),size=(1400,1250))
 if ENCLOSURE:render('assembled-neutral',allparts,direction=(.7,1,.4),size=(1400,1250))
 manifest=json.loads((ROOT/'mesh-manifest.json').read_text())
 for e in manifest:
  if e['file'].startswith('models/printable/'):
   render('part-'+e['model_id'],[{'file':e['file'],'matrix':np.eye(4).tolist(),'color':WHITE if e['model_id'] in ['camera-pod-rain-hood','camera-pod-integrated-camera-hood','camera-pod-electronics-cover'] else BLACK}],direction=(.45,-1,.85),size=(800,580))
 # Exact retained groups, with displacements only for exploded illustrations.
 fixed=[p for p in openparts if p['group']=='fixed' and p['name'] not in ['pan-servo','pi','converter','capacitor'] and not any(p['name'].startswith(q) for q in ['pi-','pan-servo-','converter-','capacitor-'])]
 def frame_ex(p):
  n=p['name']
  if n=='deck' or n.startswith('frame-upper') or n.startswith('frame-nut'):return T(0,0,25)
  if n.startswith('spider-spacer'):return T(0,0,8)
  if n=='pan-mount' or n.startswith('frame-bolt') or n.startswith('frame-lower'):return T(0,0,-18)
  return T()
 render('frame-exploded',shift(fixed,frame_ex),direction=(.3,-1,.6),size=(1550,1200))
 deckparts=[p for p in openparts if p['name']=='deck' or p['name'] in ['pi','converter','capacitor'] or any(p['name'].startswith(q) for q in ['pi-','converter-','capacitor-'])]
 render('deck-loaded',deckparts,direction=(.25,-1,1.1),size=(1500,1000))
 render('deck-top',deckparts,direction=(0,0,1),up=(0,1,0),size=(1500,950))
 pan=[p for p in openparts if p['name'] in ['pan-mount','pan-servo'] or p['name'].startswith('pan-servo-')]
 render('pan-servo-insertion',shift(pan,lambda p:T() if p['name']=='pan-mount' else T(0,0,-8 if 'bolt' in p['name'] else 36)),direction=(.65,-1,.4),size=(1100,1150))
 horn=[p for p in openparts if p['name'] in ['pan-yoke','pan-horn','pan-horn-retainer','pan-horn-center-screw'] or p['name'].startswith('pan-retainer-')]
 def horn_ex(p):
  if p['name']=='pan-yoke':return T()
  if p['name']=='pan-horn':return T(0,0,7)
  if p['name']=='pan-horn-center-screw':return T(0,0,-10)
  if p['name']=='pan-horn-retainer':return T(0,0,15)
  if 'bottom-washer' in p['name'] or 'nut' in p['name']:return T(0,0,-7)
  return T(0,0,20)
 render('pan-horn-exploded',shift(horn,horn_ex),direction=(.5,-1,.55),size=(1250,1150))
 tilt=[p for p in openparts if p['name']=='pan-yoke' or p['name'].startswith('tilt-servo')]
 if ENCLOSURE:
  render('tilt-servo-insertion',tilt,direction=(-.7,-.7,1.2),size=(1400,1000))
 else:render('tilt-servo-insertion',shift(tilt,lambda p:T() if p['name']=='pan-yoke' else T(10 if 'bolt' in p['name'] else -20)),direction=(-1,-.7,.4),size=(1400,1000))
 camera=[p for p in assembly(cover=False) if p['group']=='tilt' and p['name']!='tilt-horn-center-screw' and not p['name'].startswith('tilt-retainer') and p['name'] not in ['tilt-horn','tilt-horn-retainer','pivot-nut'] and not p['name'].startswith('pivot-')]
 def cam_ex(p):
  n=p['name']
  if n=='camera':return T(0,0,-12)
  if n=='camera-hood':return T(0,0,-26)
  if n=='camera-cowl':return T(0,0,20)
  if n.startswith('camera-cowl-nut'):return T(0,0,26)
  if 'bolt' in n or 'front-washer' in n:return T(0,0,-32)
  if 'nut' in n or 'back-washer' in n:return T(0,0,7)
  return T()
 render('camera-exploded',shift(camera,cam_ex),direction=(.8,-1,-.12),size=(1300,1150))
 gimbal=[p for p in openparts if p['group']!='fixed' or p['name'] in ['pan-mount','pan-servo'] or p['name'].startswith('pan-servo-')]
 render('gimbal-front',gimbal,direction=(.8,-1,.03),size=(1400,1250))
 render('gimbal-bottom',gimbal,direction=(-.4,-1,-.6),size=(1400,1000))
 pivot=[p for p in openparts if p['name'] in ['pan-yoke','tilt-pivot-support','camera-cradle','pivot-bolt','pivot-outer-washer','pivot-gap-shim','pivot-nut'] or p['name'].startswith('pivot-support-')]
 def pivot_ex(p):
  n=p['name']
  if n=='camera-cradle':return T()
  if n=='tilt-pivot-support' or n.startswith('pivot-support-'):return T(14,0,0 if ENCLOSURE else -10)
  if n in ['pivot-bolt','pivot-outer-washer']:return T(16)
  if n=='pivot-nut':return T(0,0,10)
  return T()
 render('pivot-exploded',shift(pivot,pivot_ex),direction=(1,-.7,.25),size=(1400,950))
 for n,panang,tiltang in [('motion-left',-90,70),('motion-down',0,0),('motion-right',90,70)]:
  parts=[p for p in assembly(panang,tiltang,cover=False) if p['group']!='fixed' or p['name'] in ['pan-mount','pan-servo']]
  render(n,parts,direction=(.6,-1,.05),size=(1000,1000))
 cover=[p for p in allparts if p['name'] in ['electronics-cover','rain-hood'] or p['name'].startswith('cover-')]
 render('cover-fit',assembly(cover=False)+shift(cover,lambda p:T(0,0,25)),direction=(.5,-1,.55),size=(1500,1300))
 if ENCLOSURE:
  bare=openparts
  base=[p for p in allparts if p['name']=='enclosure-base']
  render('base-and-spider',[p for p in bare if p['name']=='spider']+shift(base,lambda p:T(0,0,35)),direction=(.5,-1,.6),size=(1500,1100))
  render('enclosure-exploded',shift(allparts,lambda p:T(0,0,55) if p['name']=='rain-hood' or p['name'].startswith('cover-nut') else T(0,0,-35) if p['group']!='fixed' else T()),direction=(.6,-1,.45),size=(1550,1400))
  # Explode the single outer body away from the separately assembled carrier.
  fit=[p for p in assembly(cover=False) if p['group']!='fixed' or p['name'] in ['spider','pan-mount','pan-servo'] or p['name'].startswith('pan-servo-')]
  render('head-fit',shift(fit,lambda p:T(0,0,40) if p['name'].startswith('head-bolt-') or p['name'].startswith('head-upper-washer-') else T(0,0,-35) if p['name']=='gimbal-head' or p['name'].startswith('head-') else T()),direction=(.6,1,.35),size=(1450,1200))
  render('head-open-top',[p for p in allparts if p['group']!='fixed'],direction=(.1,-.2,1),size=(1500,1100))
  service=json.loads((ROOT/'service-check.json').read_text())
  route={'file':service['fixed_power_route']['file'],'matrix':np.eye(4).tolist(),'color':(.85,.55,.14)}
  render('power-route',[p for p in assembly(cover=False) if p['name']!='enclosure-base']+[route],direction=(.5,1,.15),size=(1500,1200))
  render('wiring-bottom',[p for p in allparts if p['name'] in ['enclosure-base','deck']],direction=(.05,-.2,-1),size=(1550,1050))
  render('hood-nut-seats',[p for p in allparts if p['name']=='rain-hood' or p['name'].startswith('cover-nut')],direction=(.4,-1,-.65),size=(1500,1100))
  camera_rear=[p for p in allparts if p['group']=='tilt' and (p['name'] in ['camera-cradle','camera','camera-hood'] or p['name'].startswith('camera-'))]
  render('camera-rear',camera_rear,direction=(.8,-1,.5),size=(1400,1050))
 render('overview-exploded',shift(allparts,overview_ex),direction=(.6,-1,.28),size=(1400,1800))
 (ROOT/'figure-manifest.json').write_text(json.dumps(v.manifest,indent=2)+'\n')
 (ROOT/'assembly-manifest.json').write_text(json.dumps({'configuration':CONFIG,'pose':{'pan_deg':0,'tilt_deg':0,'cover':True},'parts':allparts},indent=2)+'\n')
 # Portable colored scene for inspecting the actual checked mesh assembly.
 import trimesh
 scene=trimesh.Scene()
 for p in allparts:
  m=trimesh.load_mesh(ROOT/p['file']);m.visual.face_colors=[int(v*255) for v in p['color']]+[255]
  scene.add_geometry(m,node_name=p['name'],transform=np.array(p['matrix']))
 scene.apply_transform(np.diag([.001,.001,.001,1]))
 (ROOT/(ARTIFACT+'-assembled.glb')).write_bytes(scene.export(file_type='glb'))
if __name__=='__main__':main()

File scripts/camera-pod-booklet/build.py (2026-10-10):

"""Build and check the camera pod bench assembly booklet and STL pack from current CAD."""
from pathlib import Path
import argparse,ast,re,hashlib,json,shutil,subprocess,sys,zipfile
from datetime import date
from collections import Counter
from model_selection import selected_models

HERE=Path(__file__).resolve().parent
REPO=HERE.parents[1]

def write_evidence(root,publish=False):
    root=Path(root).resolve()
    config=json.loads((root/'configuration.json').read_text())
    enclosure=config['variant']=='enclosure'
    artifact='ARBI-camera-pod-enclosure' if enclosure else 'ARBI-camera-pod-bench'
    integration=json.loads((root/'integration-check.json').read_text())
    service=json.loads((root/'service-check.json').read_text())
    assert not integration['neutral_collisions'] and not integration['motion_grid']['failures']
    assert all(s['stop_detected'] for s in integration['hard_stop_overtravel'].values())
    assert not any(s['failures'] for s in service['assembly_paths'])
    assert not any(s['hits'] for s in service['tool_access'])
    assert not any(s['hits'] for s in service['view_check']['poses'])
    assert service['proud_head_regression_control']['expected_collision_detected']
    meshes=json.loads((root/'mesh-manifest.json').read_text())
    for e in meshes:
        assert hashlib.sha256((root/e['file']).read_bytes()).hexdigest()==e['stl_sha256'],e['file']
    assert not any(s['hits'] for s in service.get('wiring_ports',[]))
    if enclosure:
        assert not integration['head_taper']['failures']
        assert integration['neck_clearance']['minimum_clearance_mm']>=1.4
        assert integration['neck_clearance']['oversized_neck_control']['collision_detected']
        assert not service['fixed_power_route']['failures']
        assert service['fixed_power_route']['incorrect_straight_route_control']['expected_collision_detected']
        cradle=json.loads((root/'cradle-check.json').read_text())
        assert cradle['weak_joint_control']['detected']
    evidence={'date':date.today().isoformat(),'configuration':config,'status':'CAD-only; concept-unvalidated',
      'integration':integration,'service':service,
      'mesh_hashes':{e['model_id']:e['stl_sha256'] for e in meshes},
      'checker_sources':{name:hashlib.sha256((root/'source'/name).read_bytes()).hexdigest()
         for name in ['integration.py','check_integration.py','check_service.py','reference-parts.scad']+(['check_cradle.py'] if enclosure else [])}}
    if enclosure:evidence['cradle']=cradle
    relative=Path('assemblies/camera-pod')/('camera-pod-enclosure-check.json' if enclosure else 'camera-pod-geometry-check.json')
    (root/'source/arbi-hardware'/relative).write_text(json.dumps(evidence,indent=2)+'\n')
    (root/relative.name).write_text(json.dumps(evidence,indent=2)+'\n')
    if publish:(REPO/'hardware'/relative).write_text(json.dumps(evidence,indent=2)+'\n')
    provenance=json.loads((root/'source-provenance.json').read_text())
    provenance['source_hashes']={str(p.relative_to(root)):hashlib.sha256(p.read_bytes()).hexdigest()
      for p in sorted((root/'source').rglob('*')) if p.is_file() and '__pycache__' not in p.parts}
    (root/'source-provenance.json').write_text(json.dumps(provenance,indent=2)+'\n')
    return artifact

def finalize_package(root,publish=False):
    root=Path(root).resolve();artifact=write_evidence(root,publish)
    archive=root/(artifact+'-STL-pack.zip')
    members=[root/(artifact+'-assembly-STL.pdf'),root/(artifact+'-assembled.glb'),root/'README.md']+list(root.glob('*.json'))
    for name in ['models','source','figures']:
        members += [p for p in (root/name).rglob('*') if p.is_file() and '__pycache__' not in p.parts]
    with zipfile.ZipFile(archive,'w',zipfile.ZIP_DEFLATED,compresslevel=9) as z:
        for p in sorted(members):z.write(p,Path(artifact+'-STL-pack')/p.relative_to(root))
    with zipfile.ZipFile(archive) as z:
        assert z.testzip() is None
        assert sum(n.endswith('.stl') for n in z.namelist())==len(json.loads((root/'mesh-manifest.json').read_text()))
    if publish:
        target=REPO/'docs/assemblies/camera-pod/booklet';target.mkdir(parents=True,exist_ok=True)
        for name in [artifact+'-assembly-STL.pdf',artifact+'-STL-pack.zip']:
            shutil.copy2(root/name,target/name)
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

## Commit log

2026-08-30 feat: establish ARBI open engineering monorepo
    [camera-pod-envelope.scad, camera-pod-spider.scad, dock-funnel.scad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]
2026-09-08 Revise winch drum study and document delivery tracking
    [winch-drum.scad]
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2026-09-09 Add linked BOM item pages and winch prototype CAD
    [winch-bearing-cap.scad, winch-bearing-lower.scad, winch-coupling-guard.scad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]
2026-09-27 Add passive winch drilling template and desk feet
    Add the three-page 1:1 drilling PDF with a reproducible generator, and register short and long OpenSCAD desk feet as an optional bench kit. Include printing, mounting and export instructions plus mesh and fastener-clearance checks. Keep generated STL files outside Git per repository conventions.
    [winch-desk-foot-long.scad, winch-desk-foot-short.scad]
2026-09-27 Fix coupling cover clearance and add STL assembly booklet
    Widen the cover motor end for the mounting hardware envelope, retain its stand interface, and add an interference/removal regression. Update cover and reference revisions to 0.1.1 with BOM and geometry evidence.
    Add the reproducible STL/PDF pipeline, revised 14-page booklet and requested downloadable model/source bundle. Include the reusable assembly-booklet skill and nominal purchased-part geometry.
    Validation: 23 OpenSCAD entrypoints; 45 STL mesh/hash checks; 665 passive and 684 powered clearance pairs plus 284 insertion checks each; BOM and Markdown checks; rendered PDF review. Physical fit remains unverified.
    [reference-parts.scad, winch-coupling-guard.scad, winch-mount.scad]
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2026-09-28 Add payload bench mounts and checked STL assembly booklet
    Add the electronics deck, servo brackets, stock-horn retainers, camera cradle, removable pivot support, hood, cover, spacers and fit coupon. Check nominal hardware, 555 motion poses, assembly paths, 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
    [payload-assembly.scad, payload-camera-cradle.scad, payload-camera-hood.scad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]
2026-10-01 Add concept-unvalidated camera-pod payload CAD models.
    The gimbal had no manufacturing source, and the chassis only had the spider; this registers the rest of the printed kit without claiming fit or print evidence.
    [camera-gimbal-base.scad, camera-gimbal-camera-plate.scad, camera-gimbal-optical-hood.scad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]
2026-10-06 docs(hardware): align assembly fastener instructions
    Clarify servo-ear screw orientation and specify M8 locknuts consistently. Refresh the winch PDF and affected source-pack documentation while preserving checked geometry and meshes.
2026-10-07 feat(configuration): define capabilities and calibration identity (#84)
    * feat(configuration): define calibrated revision and apply contracts
    * fix(configuration): serialize persistence callbacks and stable acknowledgements
2026-10-07 chore(ci): skip CAD validation when model inputs are unchanged
2026-10-07 feat(design): adopt integrated white-shell black-core conventions
    [dock-funnel.scad, dock-nest.scad, top-pulley-keeper.scad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]
2026-10-07 feat(hardware): add integrated payload rain enclosure
    [payload-assembly.scad, payload-camera-cowl.scad, payload-electronics-deck.scad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]
2026-10-07 feat(design): publish integrated pod references and matching assembly guides
    [camera-gimbal-base.scad, camera-gimbal-camera-plate.scad, camera-gimbal-optical-hood.scad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]
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2026-10-07 feat(winch): add modular full assembly cover
    [reference-parts.scad, winch-cover-assembly.scad, winch-cover-cable-anchor.scad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]
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2026-10-07 feat(audit): define versioned event contracts and evidence semantics (#85)
    * feat(audit): define versioned event contracts and evidence semantics
    * fix(audit): preserve device interruption reason
    * fix(audit): retain controller denial after server authorization
    * fix(audit): bind outcomes to trusted context and commands
2026-10-07 feat(enrollment): add proof-bound device inventory lifecycle (#93)
    * feat(enrollment): add proof-bound device inventory lifecycle
    * feat(enrollment): integrate accepted audit and isolated server evidence
    * fix(enrollment): prevent credential key reuse across installations
2026-10-07 fix(winch): export powered transition hood separately
    [winch-cover-powered-transition.scad]
2026-10-07 feat(edge): add supervised diagnostic runtime and local adapters (#97)
    * feat(edge): implement supervised local diagnostic adapters
    * fix(edge): settle shutdown during listener startup
    * fix(ci): stage pinned Node for edge service verification
    * fix(ci): isolate resource-intensive workspace test suites
    * fix(ci): isolate embedded database fixtures from V8 Wasm code GC
2026-10-07 feat(hardware): generate line-art assembly booklets in CI (#98)
    * Build line-art assembly booklets in CI and CAD releases
    * fix(dashboard): keep media test clock aligned with the Blob SDK
    [build.py, build_booklet.py, render_figures.py]
2026-10-07 feat(winch): conceal enclosure fasteners (#103)
    * feat(winch): conceal enclosure fasteners
    * docs(winch): refresh concealed-fastener booklet pack
    [winch-cover-assembly.scad, winch-cover-clip.scad, winch-cover-passive-fascia.scad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]
2026-10-07 feat(traffic): implement durable device and WAN metering (#102)
    * feat(traffic): implement durable device and WAN metering
    * fix(traffic): retain uncertain in-flight and clock windows as gaps
    * docs(traffic): record native Linux counter comparison evidence
    * fix(edge): include consumed traffic code in build provenance
    * fix(traffic): require explicit application observation freshness
    * fix(traffic): preserve receive errors through download cleanup
2026-10-07 feat(corner-station): add round-pole pulley mount concept
    [pole-pulley-mount-assembly.scad, pole-pulley-mount-front.scad, pole-pulley-mount-rear.scad]
2026-10-07 fix(corner-station): bound OpenSCAD version probe
2026-10-07 feat(site): add arbi-docs app with website direction mockups
    Add apps/arbi-docs, the planned public Next.js/Tailwind site for
    arbi.gredice.com. scripts/compile-data.mjs compiles the CAD registry, BOM
    reports, documents and committed booklet packs (GLB, STL meshes, assembly
    and figure manifests, line-art figures) into ignored public data at build
    time, so the app holds no copies of repository content.
    The first slice hosts three direction mockups (index, studio, manual) with
    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
2026-10-07 feat(site): add manual + ink direction mockup
    Combine the manual (C) system with full-black inverted sections for
    exploded views: a scroll-driven teardown cover on the home page and black
    system stages, drawn as inverted line art from the same booklet meshes.
    The shared viewer gains an "ink" line-art style.
2026-10-07 feat(site): read exploded poses, meshes and downloads from CAD outputs
    Remove the website-authored explode rules. The site now reads exploded
    poses from the booklet renderer's figure manifests, and the payload
    renderer gains an overview-exploded figure: a whole-assembly teardown
    that the site prefers once a pack contains it.
    compile-data resolves the latest cad-<commit> release, checks assets
    against SHA256SUMS.txt, uses release booklet packs only when their meshes
    match the current registry, and otherwise falls back to the committed
    snapshots. Dock and corner-station parts get 3D from verified release STLs
    as a labelled parts layout. Every model download is resolved at build
    time: a releas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
    [render_figures.py]
2026-10-07 fix(site): pure white and neutral gray inverted line art; scene data merge
    Inverted line art now uses pure white for white shells and untinted grays
    for the charcoal core and bought metal, with tone mapping disabled so the
    flat colors render exactly. Site grays are neutral too. Camera fits leave
    room for the exploded pose.
    Fix the scene loader: site.json's part count overwrote each scene's parts
    array, which left the site blank.
2026-10-07 feat(winch): add round-pole saddles and bottom cable routing
    [reference-parts.scad, winch-cover-assembly.scad, winch-cover-passive-left.scad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]
2026-10-07 feat(site): rebuild the site as statically generated Next.js routes
    Replace the single client-routed page with App Router routes generated at
    build time: the cover teardown, /systems/[slug], /parts/[id], /bom/[id],
    /docs/[...slug] and /downloads (233 pages). Server components read the
    data compiled by scripts/compile-data.mjs (now public/data); documents
    render from Markdown at build time with repository links mapped to site
    routes. The three.js viewer is a typed module used by client components
    for the cover, the exploded-view stages and part views. Tailwind CSS,
    three.js, marked and the fonts are bundled; nothing loads from CDNs.
    Links from the earlier single-page site are forwarded to th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
2026-10-07 fix(ci): mark the newest CAD release Latest when main has moved on
    The release was marked Latest only if its commit was still main's head
    when publishing finished. Booklet builds take 15-20 minutes, so merges
    during that window left Latest on an old snapshot (cad-2812031) while
    newer releases were published unmarked, and the public site reads Latest.
    Mark the release Latest unless the current Latest belongs to a newer
    commit, using the compare API: ahead or identical means this release is
    at least as new. Runs stay serialized by the concurrency group.
2026-10-08 feat(ci): rebuild the public site when a CAD release becomes Latest
    The site reads the Latest CAD release at build time, so a release that
    finished after the merge's own deployment only appeared at the next deploy.
    After publishing a Latest release, call the arbi project's cad-release
    Vercel deploy hook (ARBI_SITE_DEPLOY_HOOK secret) to rebuild production.
    The refresh is skipped with a notice when the secret is absent and does
    not fail the run, since the release is already published.
2026-10-08 feat(payload): compact the integrated enclosure and covered gimbal
    [camera-pod-assembly.scad, payload-assembly.scad, payload-enclosure-base.scad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]
2026-10-08 fix(ci): let an unreachable Latest commit not block releases; hedge refresh docs
    If the current Latest release's commit can no longer be compared (HTTP 404,
    for example after a force-push), mark this run's main commit Latest instead
    of failing every later release. Other compare errors still fail the step.
    The READMEs now say the site rebuild is requested only when the deploy hook
    secret is configured, and that a failed request does not fail the release.
2026-10-08 fix(docs): outline rounded CAD surfaces in the 3D viewer (#116)
2026-10-08 fix(bom): record WASI and Dive Store purchase costs (#115)
    * fix(bom): record WASI BA01090 purchase and store pickup
    * fix(bom): confirm Dive Store spool price and Zagreb delivery
2026-10-08 feat(camera-pod): connect tray and gimbal underside (#117)
    [camera-pod-assembly.scad, payload-assembly.scad, payload-enclosure-base.scad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]
2026-10-08 fix(docs): generate previews for every registered CAD part (#123)
    [build.py]
2026-10-08 fix(docs): keep CAD assemblies and versioned releases current (#121)
    * fix(docs): publish source-matched versioned CAD releases
    * fix(releases): reject incomplete publication assets
    * fix(releases): honor explicit semantic version bumps
    * fix(docs): surface current guides on archived booklet pages
    * fix(docs): distinguish pending CAD previews from missing models
2026-10-08 fix(cad): compact release history before publication (#127)
2026-10-08 fix(winch): align cables with ports in exploded views (#125)
    [render_figures.py]
2026-10-08 fix(bom): align columns across assembly tables (#129)
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2026-10-08 fix(parts): consolidate camera pod and render inventory as line art (#126)
    * fix(parts): consolidate camera pod and render inventory as line art
    * fix(cad): keep release metadata within publication output buffer
    * fix(cad): render reference components without assembly unions
    * fix(cad): read and write reference geometry as UTF-8
    [build.py]
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2026-10-08 fix(winch): route looms under motor and link bought hardware (#132)
    * fix(winch): connect loom references and link bought hardware
    * fix(winch): keep extended motor looms clear of each other
    * fix(winch): avoid guessing owners of archived fasteners
    [render_figures.py]
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2026-10-08 fix(bom): allocate and display bundle costs by part count (#135)
    * fix(bom): allocate and display bundle costs by part count
    * fix(bom): reject duplicate part IDs in bundle contents
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2026-10-08 fix(hardware): archive superseded camera pod models (#139)
    [build.py, export_models.py, model_selection.py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]
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2026-10-08 feat(hardware): add printable corner support head and assembly pack (#137)
    * feat(hardware): add corner support nominal design package
    * feat(hardware): redesign corner head for printed carriers
    [corner-head-assembly.scad, corner-head-front-saddle.scad, corner-head-hood.scad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]
2026-10-09 fix(camera-pod): finish naming migration and remove duplicate assembly (#141)
    * fix(camera-pod): complete naming migration and consolidate assembly
    * fix(bom): exclude generated booklet copies from geometry evidence
    * docs(camera-pod): finish captions from latest main
    [camera-pod-assembly.scad, camera-pod-camera-cowl.scad, camera-pod-camera-cradle.scad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]
2026-10-09 feat(parts): cover every BOM item with documented 3D geometry (#143)
    [as5600-angle-sensor.scad, bearing-608-2rs.scad, bulk-capacitor-1000uf.scad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]
2026-10-09 fix(hardware): reinforce compact camera cradle joints (#142)
    [camera-pod-assembly.scad, camera-pod-integrated-camera-cradle.scad]
2026-10-09 fix(hardware): assign positioning lines to corner winches (#144)
    * fix(hardware): assign positioning lines to corner winches
    * docs(winch): clarify line-side strain relief ownership
    [capsule-slip-ring-6x2a.scad, dyneema-positioning-line.scad, pod-power-wire-black-awg26.scad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]
2026-10-09 feat(dock): add supported bench capture kit and assembly guide (#145)
    * feat(dock): add supported bench capture kit and assembly guide
    * fix(dock): require current assembly in public release verification
    * docs(dock): distinguish physical tests from nominal CAD checks
    [dock-arm-extension.scad, dock-arm-root.scad, dock-assembly.scad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]
2026-10-09 feat(control-cabinet): add assembly layout and interactive preview (#146)
    * feat(control-cabinet): add assembly layout and interactive preview
    * fix(control-cabinet): address preview validation and navigation review
    [control-cabinet-assembly.scad, controller-buck-converter-48v-5v.scad, din-rail-ground-distribution-block.scad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]
2026-10-10 feat(corner-station): add printable WT-806 stand adapters (#148)
    [corner-stand-assembly.scad, corner-stand-head-front.scad, corner-stand-head-rear.scad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]
2026-10-10 feat(systems): show mounted corner subassemblies and BOM kit contents (#149)
    * feat(systems): expose mounted corner assembly and kit BOM contents
    * fix(systems): clarify material and line keeper evidence
    * fix(cad): allow large reference meshes to finish in CI
    [cabinet-installation-kit.scad, cabinet-protection-kit.scad, camera-pod-fastener-kit.scad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]
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2026-10-10 feat(cad): adopt pinned BOSL2 for shared shapes and sampled surfaces (#155)
    * feat(cad): adopt pinned BOSL2 helpers and portable library sources
    * chore(cad): refresh print evidence and stabilize validation
    * fix(cad): extrude rounded profiles for clean adapter cuts
    * fix(cad): verify portable source dependency closure
    [build.py]
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2026-10-11 feat(audit): authorized search, bounded exports and receipted retention (#162)
    * feat(audit): authorize bounded investigations and receipted retention
    * fix(audit): select retention policy in serialized insertion order
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2026-10-11 Add bounded live viewer sessions and shared producer authority (#169)
    * feat(live): add bounded audited viewer session authority
    * fix(live): handle expired site leases and legacy policy history
    * test(dashboard): remove trace and fake-clock browser races
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2026-10-11 Add inhibited Pico 2 W firmware foundation and pinned cross-build (#178)
    * feat(firmware): add inhibited Pico 2 W diagnostic foundation (#31)
    * docs: record clean Pico cross-build and sanitizer evidence
    * fix(firmware): recover setup and validate configuration atomically
    * docs: record reviewed firmware foundation checks
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2026-10-11 feat(corner-station): add illustrated WT-806 mounting instructions (#182)
    * feat(corner-station): add illustrated WT-806 mounting instructions
    * fix(booklet): keep dock helper imports independent of stand insert
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2026-10-11 Fence local controller model commands and require deliberate recovery (#184)
    * feat(firmware): fence local model commands and deliberate recovery (#67)
    * fix(firmware): bound reset enum for the ARM compiler
    * docs: record clean controller recovery model evidence
2026-10-11 feat(corner-station): fit measured Barton N01090 pulley (#187)
    * feat(corner-station): model measured Barton pulley and mating lugs
    * fix(corner-station): print current booklet revision
2026-10-11 Expose bounded MCU model diagnostics and traceable command outcomes (#186)
    * feat(firmware): retain bounded model diagnostics and command outcomes (#70)
    * fix(firmware): bind diagnostic format fallback to the target ABI
    * docs: record clean bounded diagnostics source evidence
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2026-10-11 Add inhibited pod runtime with authenticated diagnostics and health provenance (#181)
    * feat(pod): add inhibited supervised diagnostic service (#32)
    * test(pod): exercise valid actuator denial and safe benchmark cleanup
    * docs(pod): record clean process and dependency checks
    * fix(pod): cancel pending startup after shutdown
    * docs(pod): record clean startup cancellation checks
2026-10-11 Model calibrated gimbal limits and local settling interlocks (#190)
    * feat(pod): model calibrated gimbal limits and local settling interlocks (#42)
    * fix(pod): inhibit failed gimbal adapters and bound admission outcomes
    * fix(pod): preserve safe gimbal pose during normal main motion
    * docs: record clean gimbal model and physical acceptance gaps
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2026-10-11 Rectify calibrated synthetic images with explicit quality and raw fallback (#192)
    * Add bounded calibrated image processing and explicit raw fallback
    * Record clean image fixture and Linux resource evidence
2026-10-11 Compose traceable capture jobs, offline staging and verified media uploads (#194)
    * Compose stopped capture jobs, native offline stages and verified media uploads
    * Bind capture job proofs to the requested pod identity and provenance
    * Drain capture uploads even when preview audit persistence fails
    * Distinguish locally extracted preview frames from observed viewer delivery
    * Record clean capture composition and native media acceptance evidence
    * Record the passing native edge regression
    * Build independent native edge test adapter before dashboard typechecking
    * Preserve native Node loading for private workspace adapter subpaths
    * Record preview build and independent adapter build o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
2026-10-11 Measure a local WebRTC candidate and record unresolved hardware gates (#196)
    * Add reproducible local WebRTC candidate measurements for issue 43
    * Record clean local RTP and browser resource measurements
    * Keep browser checks cross-platform and fail before opening unsupported resources
    * Record current transport results and optional platform guard checks
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2026-10-11 Add measured host update interruption and canary evidence (#200)
    * Add reproducible host update interruption and canary evidence
    * Record clean host update interruption matrix measurements
    * Clarify outstanding qualified physical review
    * fix: bind interruption evidence to rebuilt clean source
    * docs: record rebuilt interruption evidence after review
2026-10-11 Measure controlled application and Linux usage with budget exhaustion (#202)
    * feat: measure controlled usage across application and Linux counters
    * fix: use artifact budget class for optional update probe
    * fix: retain the registered local consumer device in the usage fixture
    * docs: record controlled application and kernel usage evidence
2026-10-11 Validate staged release evidence and keep physical gates explicit (#203)
    * feat: validate staged release evidence without field authority
    * fix: require disabled capability and reserved recording contract evidence
    * docs: record missing-evidence release draft
    * docs: bind release draft to current source after integration
    * fix: require matching raw outcomes and preapproved stage procedures
    * docs: update release draft provenance
2026-10-11 Fix filtered dashboard builds missing native Edge dependencies (#204)
    * fix: compile native Edge fixtures before filtered dashboard tasks
    * docs: record filtered hosted build dependency verification
2026-10-12 feat(bom): prioritize design warnings and flag cable-tie workarounds (#205)
2026-10-12 fix(bom): separate engineering priorities from procurement issues (#208)
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2026-10-12 fix(hardware): model received 5 V buck converter and mounts (#206)
    * fix(hardware): model received 5 V buck converter and mounts
    * docs(camera-pod): align current assembly and deck revisions
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2026-10-12 fix(parts): visualize CSG reference assemblies (#213)
2026-10-12 fix(camera-pod): align measured servo mounts and shading
2026-10-12 fix(camera-pod): record accepted fit and validate booklet revisions
2026-10-12 fix(camera-pod): synchronize assembly instructions and cancel failed exports
2026-10-12 fix(cad): derive Pi 3A+ reference from official drawings (#216)
2026-10-12 fix(camera-pod): revalidate accepted servo fit with current references
2026-10-12 fix(hardware): model received KW11-3Z microswitch (#217)
    * fix(hardware): model received KW11-3Z microswitch
    * chore(hardware): refresh KW11-3Z evidence on current main
    * fix(test): stabilize native audit minute-boundary fixture
2026-10-12 fix(cad): model NEMA 23 motor from supplier drawing (#219)
2026-10-14 fix(camera-pod): fit the received Camera Module 3 Wide (#218)
    * fix(camera-pod): fit the received Camera Module 3 Wide
    * docs(camera-pod): reconcile Wide selection and historical reports
    * docs(camera-pod): correct the Wide hood print revision
2026-10-14 fix(cad): detail and shade Camera Module 3 Wide (#220)
    * fix(cad): detail and shade Camera Module 3 Wide
    * fix(cad): expose CSI contacts and select camera markings
    * fix(cad): keep camera lettering resolution consistent in assemblies
    * chore(bom): reconcile camera evidence with the accepted dock baseline
2026-10-14 fix(camera-pod): ease Wide camera cover assembly (#223)
    * fix(camera-pod): ease Wide camera cover assembly
    * fix(camera-pod): order pivot support before camera fitting
    * fix(camera-pod): open the complete CSI exit and guard its clearance
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2026-10-14 fix(docs): keep camera pod surfaces in assembly coordinates (#224)
2026-10-15 feat(dock): add removable charcoal lower enclosure (#226)
    * feat(dock): add removable charcoal lower enclosure
    * fix(dock): align rear panel module metadata
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2026-10-15 feat(camera-pod): replace ties with removable retainers (#229)
    * feat(camera-pod): replace ties with removable retainers
    * docs(camera-pod): correct assembly revision reference
2026-10-17 fix(corner-head): replace ties with removable cover screws (#231)
2026-10-17 fix(corner-head): conceal cover attachments with printed latches (#233)
    * fix(corner-head): conceal cover attachments with printed latches
    * docs(corner-head): separate cover interior views in booklet
